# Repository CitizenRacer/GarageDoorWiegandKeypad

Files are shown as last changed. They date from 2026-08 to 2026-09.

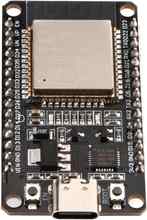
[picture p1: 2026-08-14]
docs/images/esp32s-30pin.jpg

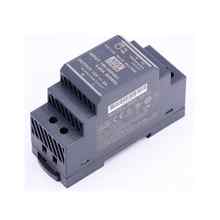
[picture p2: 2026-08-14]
docs/images/meanwell-hdr-30-12.jpg

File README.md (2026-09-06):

# Garage Door Keypad

ESPHome firmware and Home Assistant configuration for a classic ESP32-based garage-door Wiegand keypad controller.

The controller is an **ESP32S 30-pin USB-C NodeMCU development board with ESP32-WROOM-32 and CP2102**. The active outdoor reader/keypad is a **Retekess T-AC04** using Wiegand output.

## Release status

The repository firmware on `main` is **v22**. The last confirmed production deployment is **v22**.

v22 changes only the standalone `*` / `#` close shortcut. Firmware no longer trusts a cached Home Assistant garage-door state and no longer calls `cover.close_cover` directly. A standalone `*` or `#` now always delegates to the Home Assistant close-only API `script.garage_keypad_close_garage`, which refreshes RATGDO telemetry when needed and proceeds only when the refreshed state is positively `open`. Ambiguous telemetry fails closed, and this standalone path has no route that can open the garage or alter the alarm.

Valid PIN behavior remains unchanged from v21: Lock Code Manager validates the credential, invalid attempts are logged to Home Assistant Activity with the LCM reason and no PIN value, and accepted credentials call the guarded `script.garage_keypad_open_garage` flow.

The PIN path is:

```text
Retekess T-AC04 PIN
   |
   v
ESP32 key collector
   |
   | encrypted ESPHome native API
   v
lock_code_manager.use_credential
   |
   | LCM user / PIN / enabled state / conditions
   v
{ valid, user, reason }
   |
   +--> valid: script.garage_keypad_open_garage(person_name=<LCM user>)
   |
   +--> invalid: Activity entry with LCM reason; no garage action
```

The v20 production cutover established that valid physical PINs resolve to the correct LCM users, invalid PINs are rejected, PIN values do not appear in ESPHome logs, Debug Mode blocks opening during no-motion testing, and the production guarded path opens the garage after Debug Mode is intentionally disabled.

## Required runtime dependency

This project has a direct runtime dependency on **[Lock Code Manager](https://github.com/raman325/lock_code_manager)**, a Home Assistant custom integration. Use **LCM 5.3.0 or later**.

Lock Code Manager is the canonical source for keypad users and PINs. Adding, removing, enabling, disabling, or scheduling a keypad user should be done in LCM rather than by editing a YAML credential map.

The ESPHome package cannot install or enforce the presence of a Home Assistant custom integration. If LCM is missing, unavailable, or its action call fails, credential validation fails closed and firmware refuses garage operation.

For GitHub tooling, `.github/workflows/dependency-submission.yml` submits `raman325/lock_code_manager` as a **direct runtime dependency** to GitHub's Dependency Graph. This makes the relationship machine-readable in **Insights → Dependency graph** even though ESPHome YAML has no native manifest field for Home Assistant integration dependencies.

## Current access-control contract

Credential validation and physical garage operation are deliberately separate.

LCM answers **who is authorized**. `script.garage_keypad_open_garage` decides **whether and how the physical garage may move** for valid PINs. `script.garage_keypad_close_garage` is a separate close-only API for standalone `*` / `#` commands.

The guarded door-action layer uses these rules:

- If the garage cover state is exactly `open`, a valid PIN closes it. This branch does not alter the alarm.
- A standalone `*` or `#` never decides garage state in firmware. It always calls `script.garage_keypad_close_garage` when no PIN entry is in progress.
- The close-only Home Assistant script calls `cover.close_cover` immediately only when RATGDO already positively reports `open`.
- If RATGDO is not positively `open`, the close-only script presses `button.ratgdov25i_15cde7_query_status`, waits up to 3 seconds for a definitive `open` or `closed` state when needed, and requires the result to be exactly `open` before closing.
- If refreshed telemetry is `closed`, transitional, unavailable, unknown, or otherwise not positively `open`, the standalone close request does nothing. Ambiguous telemetry therefore fails closed.
- The standalone close-only script has no path that can open the garage and does not change the alarm.
- For valid PIN handling, opening is considered only when the guarded Home Assistant path positively establishes the required terminal state. Unknown, unavailable, or otherwise unsafe states fail closed.
- Opening requires `input_select.garage_keypad_alarm_restore_mode` to be exactly `none`.
- Opening requires `binary_sensor.garage_garage_keypad_debug_mode` to be exactly `off`.
- If the alarm is already disarmed, the garage may open without creating a restore marker.
- If the alarm is in a supported armed state, the script records the exact mode, disarms, positively confirms `disarmed`, records keypad ownership of that disarm, and only then opens.
- Supported armed modes are `armed_home`, `armed_away`, `armed_night`, `armed_vacation`, and `armed_custom_bypass`.
- Unsupported, unknown, unavailable, triggered, or otherwise non-disarmed alarm states block opening.
- The production live script verifies RATGDO motor activity and retries the opening request when needed before treating the operation as successful.
- When RATGDO reports `opening` or `closing` while the motor is off, the production valid-PIN script refreshes RATGDO status before deciding whether to open or close and fails closed if a definitive state cannot be established.
- Only after a confirmed actual opening does the kitchen Alexa announce `"<friendly user name> opened the garage door"`.

An LCM `lock_code_manager_credential_used` event means a credential was accepted. It is **not** proof that the garage moved; garage motion remains the responsibility of the guarded operation layer.

## Lock Code Manager configuration

The production keypad uses the lockless LCM entry **KOZ2 Locks**. Firmware uses its stable config-entry ID by default and reports the Garage Keypad as the credential source and the RATGDO cover as the target.

The firmware calls:

```yaml
lock_code_manager.use_credential
```

with:

```text
config_entry_id = configured KOZ2 Locks entry
code            = PIN entered on keypad
source          = Garage Keypad attribution entity
target          = cover.ratgdov25i_15cde7_door
```

LCM returns `valid`, `user`, and `reason`.

- `valid: true` -> firmware passes the returned friendly user name to `script.garage_keypad_open_garage`.
- `valid: false` -> firmware does not call the garage script. It logs a Home Assistant Activity entry such as `Credential rejected - Lock Code Manager reason: unknown_code`.
- action/response failure -> firmware fails closed and refuses garage operation.

No Activity entry contains the submitted PIN.

Enable **Allow the device to perform Home Assistant actions** for the Garage Keypad ESPHome integration entry. ESPHome and Home Assistant 2025.11.0 or later are required for reliable action-response capture.

## Debug Mode

v22 retains Debug Mode as an independent physical-operation safety control:

```yaml
keypad_debug_mode: "false"
```

The normal production setting is `false`. Set it to `true` only for an intentional no-motion/maintenance test and redeploy the firmware. The Home Assistant opening path fails closed unless `binary_sensor.garage_garage_keypad_debug_mode` positively reports `off`.

Debug Mode has nothing to do with credential logging. PINs are never intentionally logged in either mode. Debug Mode blocks opening but does not block closing an already-open garage.

## PIN confidentiality

There is no PIN HMAC, verifier map, HMAC generator, eFuse-key dependency, PIN sensor, or custom PIN-validation script in the v20-v22 firmware path.

The plaintext PIN exists only transiently in the ESPHome key collector and in the encrypted native-API request to `lock_code_manager.use_credential`. It is never intentionally published as an entity state, written to ESPHome logs, or written to Home Assistant Activity/Logbook.

Firmware logs only the PIN length and LCM validation result/reason. Rejected-credential Activity entries contain only the LCM reason.

## RFID status

RFID authorization is **disabled in v22**.

The firmware continues to decode and log 26/34/37-bit Wiegand RFID frames for commissioning, but it does not submit RFID IDs to LCM and does not operate the garage from an RFID credential. The LCM external-credential path used by this project is PIN-oriented; RFID identifiers are not represented as PINs simply to force them through the integration.

See [`docs/RFID_ACCESS_DESIGN.md`](docs/RFID_ACCESS_DESIGN.md).

## Wiegand diagnostics

RFID commissioning diagnostics may log:

```text
RFID tag received: <decoded credential> (authorization disabled)
Wiegand RFID/raw frame: <bits> bits, value=0x<raw>
```

The raw Wiegand logger is intentionally restricted to frames **greater than 8 bits**. It must never raw-log 4-bit or 8-bit frames because those frames are keypad keystrokes and could disclose PIN digits.

## Standalone `*` / `#` close-only behavior

Wiegand key 10 (`*`) and key 11 (`#`) have two contexts:

- after numeric PIN digits, `*` remains PIN clear and `#` remains PIN submit exactly as before;
- with no numeric PIN entry in progress, either key calls `script.garage_keypad_close_garage`.

Firmware does **not** import or inspect garage-door state for this shortcut in v22. It does not call `cover.close_cover` directly and does not route the command through `script.garage_keypad_open_garage`.

`script.garage_keypad_close_garage` is intentionally structurally close-only:

1. If RATGDO already positively reports `open`, it calls `cover.close_cover`.
2. Otherwise it presses `button.ratgdov25i_15cde7_query_status`.
3. If necessary, it waits up to 3 seconds for `open` or `closed`.
4. It requires the final state to be exactly `open` before issuing a close.
5. Any other result does nothing.

Because the script contains no open action and no alarm action, a standalone `*` / `#` command cannot open the garage or change alarm state. Stale, transitional, unavailable, unknown, or otherwise ambiguous telemetry fails closed.

## Alarm transaction and recovery behavior

The persistent ownership marker is:

```text
input_select.garage_keypad_alarm_restore_mode
```

with options:

```text
none
armed_home
armed_away
armed_night
armed_vacation
armed_custom_bypass
```

The marker means the keypad flow itself disarmed the alarm and therefore owns a pending restoration.

When the garage later closes, the companion automation restores the saved mode only when the keypad owns that restore. If somebody manually re-arms first, the automation preserves that state and clears the keypad marker.

The checked-in automation is [`homeassistant/garage-keypad-automation.yaml`](homeassistant/garage-keypad-automation.yaml).

## Hardware and wiring

Installed Wiegand signal path:

```text
T-AC04 Green D0 -> level shifter HV3/LV3 -> ESP32 GPIO22
T-AC04 White D1 -> level shifter HV2/LV2 -> ESP32 GPIO19
```

The firmware defaults to GPIO22 for D0 and GPIO19 for D1. See [`docs/BOM.md`](docs/BOM.md) for the as-built bill of materials.

## ESPHome package and Device Builder

The repository firmware package is [`esphome/garage-keypad.yaml`](esphome/garage-keypad.yaml), currently firmware **v22**.

Firmware versioning is explicit: increment `firmware_version` whenever `esphome/garage-keypad.yaml` itself is checked in with a firmware change. Documentation/workflow-only changes do **not** require a firmware-version increment.

A local Device Builder wrapper supplies secrets and imports the package from `main`. See [`esphome/device-builder-wrapper.example.yaml`](esphome/device-builder-wrapper.example.yaml).

Required local substitutions include Wi-Fi credentials, OTA password, fallback AP password, and the ESPHome API Noise key. The LCM config-entry ID and source/target entities are normal non-secret substitutions and can be overridden if the Home Assistant installation changes.

The production local wrapper should use:

```yaml
keypad_debug_mode: "false"
```

Old v19 wrapper extensions such as `generated_pin_hmac` or `keypad_debug_logging` are obsolete and must not be carried forward.

## Continuous integration

`.github/workflows/esphome.yml` validates and compiles the production ESPHome package on every push and pull request, and can also be run manually with `workflow_dispatch`. CI is pinned to **ESPHome 2026.8.2** and runs on a standard GitHub-hosted Ubuntu runner.

The workflow creates synthetic CI-only Wi-Fi, OTA, fallback-AP, and API-encryption values; no production credentials are stored in the repository or required by GitHub Actions. It validates a local package wrapper, validates the checked-in production Device Builder wrapper on `main`, and then compiles `esphome/garage-keypad.yaml` through the CI wrapper. CI only verifies that the configuration can be resolved and built; it does not deploy firmware to the physical keypad.

## Home Assistant files

[`homeassistant/garage-keypad-script.yaml`](homeassistant/garage-keypad-script.yaml) documents the common guarded valid-PIN door-action API. The production live `script.garage_keypad_open_garage` contains additional RATGDO status-refresh and motor-start verification/retry behavior; do not replace that more capable live script with the simpler checked-in baseline.

v22 also requires the live Home Assistant script `script.garage_keypad_close_garage` for standalone `*` / `#`. That script is close-only: it refreshes RATGDO status when the door is not already positively `open`, requires a final `open` state, and otherwise performs no action. It must never contain an open action or alarm-management path.

[`homeassistant/garage-keypad-automation.yaml`](homeassistant/garage-keypad-automation.yaml) contains keypad-owned alarm restoration and manual-rearm ownership-clearing logic.

Required helper:

```text
input_select.garage_keypad_alarm_restore_mode
```

The old `garage_keypad_users.yaml`, PIN HMAC validator, RFID HMAC validator, and HMAC-generation helper are obsolete for the LCM production architecture. See [`docs/LCM_MIGRATION.md`](docs/LCM_MIGRATION.md) for rollback-cleanup guidance.

## Security model

- PINs are stored and managed by Lock Code Manager.
- A keypad submission travels to Home Assistant through ESPHome's encrypted native API.
- No entity publishes the PIN, avoiding Recorder history of keypad codes.
- The firmware never intentionally logs plaintext PINs.
- Invalid-attempt Activity entries expose the LCM reason, not the submitted PIN.
- Standalone `*` / `#` close requests are delegated to a Home Assistant script that is structurally incapable of opening the garage.
- Firmware does not trust cached garage state for standalone close commands; ambiguous RATGDO telemetry is refreshed and still fails closed unless the result is positively `open`.
- A fully compromised Home Assistant installation can already directly operate the garage and is outside the keypad-validation threat model.
- The previously burned classic-ESP32 eFuse BLK3 bits cannot be erased, but v20-v22 do not read or use them.
- Debug Mode remains an absolute opening lockout, not a closing lockout.

## Migration and rollback

The v19 HMAC-to-v20 LCM production cutover is complete. v22 retains the same LCM credential architecture and v21 rejection logging; it changes only the standalone close shortcut to delegate all state validation to the Home Assistant close-only script.

See [`docs/LCM_MIGRATION.md`](docs/LCM_MIGRATION.md) for the completed validation record and remaining rollback cleanup.

Until the old live HMAC scripts/file are intentionally removed, reinstalling v19 remains a rollback option. Once those live rollback artifacts are deleted, LCM is the sole supported credential authority.

## Repository structure

```text
GarageDoorWiegandKeypad/
├── .github/
│   └── workflows/
│       ├── dependency-submission.yml
│       └── esphome.yml
├── README.md
├── cad/
├── docs/
│   ├── BOM.md
│   ├── LCM_MIGRATION.md
│   └── RFID_ACCESS_DESIGN.md
├── esphome/
│   ├── garage-keypad.yaml
│   └── device-builder-wrapper.example.yaml
└── homeassistant/
    ├── garage-keypad-script.yaml
    └── garage-keypad-automation.yaml
```

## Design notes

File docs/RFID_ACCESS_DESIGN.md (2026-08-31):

# RFID access status

Production firmware v20 deliberately **does not authorize RFID credentials**.

The Retekess T-AC04 and ESPHome Wiegand component still decode 26-, 34-, and 37-bit RFID frames, and commissioning diagnostics remain available:

```text
RFID tag received: <decoded credential> (authorization disabled)
Wiegand RFID/raw frame: <bits> bits, value=0x<raw>
```

Raw logging remains restricted to frames greater than 8 bits so 4-bit/8-bit keypad keystroke frames are never raw-logged.

## Production behavior

The v20 production cutover validated PIN access through Lock Code Manager. RFID was intentionally excluded from that cutover and cannot operate the garage.

The rule is:

```text
RFID frame -> decode/diagnose -> NO authorization -> NO garage action
```

An RFID frame does not call `lock_code_manager.use_credential`, does not call `script.garage_keypad_open_garage`, and does not open or close the garage.

## Why authorization is disabled

The project moved PIN management to Lock Code Manager in v20 and removed the custom HMAC credential system from the firmware path. Although LCM has credential-type concepts, the managed external-credential path currently used by this project is PIN-oriented.

Treating a raw RFID identifier as a PIN would create misleading credential semantics and make a later proper RFID migration harder. The old HMAC-based RFID authorization path should not be reintroduced as an interim design.

## Diagnostics and confidentiality

RFID commissioning logs can expose decoded/static RFID identifiers to anyone who can read ESPHome logs. Those identifiers should therefore be treated as credential material even though RFID authorization is disabled.

The raw Wiegand logger must continue to enforce `bits > 8`. Four-bit and eight-bit frames are keypad keystrokes and must never be raw-logged because doing so could expose PIN digits.

## Future target

When Lock Code Manager supports the intended RFID credential type end to end for external readers, the target flow is:

```text
T-AC04 RFID
   |
   v
ESPHome Wiegand decoder
   |
   v
LCM RFID credential validation
   |
   v
friendly user
   |
   v
guarded script.garage_keypad_open_garage
```

At that point the project should use LCM's real RFID credential type and unified credential-used event while preserving the same guarded physical-operation layer used by PINs.

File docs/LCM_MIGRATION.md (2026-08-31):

# Lock Code Manager migration

## Status

The v19 HMAC-to-v20 Lock Code Manager migration is **complete in production**.

Firmware v20 is merged to `main`, deployed to the physical Garage Keypad, and validated through the full production path. Lock Code Manager is now the canonical PIN/user store.

The only remaining migration work is optional rollback cleanup on the live Home Assistant instance: remove the obsolete v19 HMAC validators, HMAC generator, and credential-map file after deciding that v19 rollback is no longer needed.

## Production architecture

```text
Retekess T-AC04 PIN
   |
   v
ESPHome v20 key collector
   |
   | encrypted native API
   v
lock_code_manager.use_credential
   |
   v
{ valid, user, reason }
   |
   +--> valid: script.garage_keypad_open_garage(person_name=<LCM user>)
   |
   +--> invalid: stop; no garage action
```

LCM owns credential validity and user identity. `script.garage_keypad_open_garage` remains the guarded physical-operation layer and must not be bypassed.

## Completed cutover record

### 1. LCM population and direct validation — complete

The production lockless `KOZ2 Locks` entry was populated with the intended production keypad users/PINs and validated with `lock_code_manager.use_credential` before firmware cutover.

Expected response fields are:

```text
valid
user
reason
```

Invalid reasons observed/expected include `unknown_code`, `user_disabled`, and `condition_not_met`.

### 2. v20 merged to `main` — complete

Pull request #1, `Firmware v20: migrate keypad PIN validation to Lock Code Manager`, was merged from `lcm-native-credentials` into `main`.

The firmware remains version `20`; the merge itself did not create a new firmware version.

### 3. First v20 deployment with Debug Mode on — complete

The local Device Builder wrapper was updated for v20 and deployed with:

```yaml
substitutions:
  keypad_debug_mode: "true"
```

Stale v19 wrapper configuration referencing `generated_pin_hmac` was removed because that entity no longer exists in v20.

Home Assistant then reported firmware version `20` and Debug Mode `on`.

### 4. Physical no-motion test — passed

Physical keypad submissions were tested while Debug Mode remained on.

Observed results:

- valid physical PIN submissions reached `lock_code_manager.use_credential`;
- LCM resolved valid credentials to the correct friendly users;
- invalid PINs were rejected as `unknown_code`;
- invalid credentials did not reach the guarded garage-operation path;
- ESPHome logs contained PIN length and validation results but not the actual PIN values;
- accepted credentials did not move the garage while Debug Mode was on.

This verified the intended chain through the physical Wiegand keypad, ESPHome key collector, LCM, and the guarded Home Assistant operation script without allowing door motion.

### 5. Production deployment with Debug Mode off — complete

After the no-motion test passed, v20 was redeployed with:

```yaml
keypad_debug_mode: "false"
```

The Debug Mode binary sensor reported `off`.

A valid physical keypad PIN then successfully opened the garage through the normal v20 LCM path and the existing guarded `script.garage_keypad_open_garage` operation layer.

The production cutover is therefore complete.

## Current production requirements

- Lock Code Manager remains the canonical PIN/user database.
- Garage Keypad ESPHome integration must retain **Allow the device to perform Home Assistant actions**.
- ESPHome and Home Assistant 2025.11.0 or later are required for reliable `homeassistant.action` response capture.
- Production `keypad_debug_mode` should be `"false"`.
- The guarded `script.garage_keypad_open_garage` must remain the only valid-credential path to physical garage operation.
- The production live garage script's RATGDO motor-start verification/retry behavior should be preserved.
- PIN values must never be intentionally logged or exposed as entity state/history.
- Raw 4-bit and 8-bit Wiegand frames must never be logged.
- RFID authorization remains disabled in v20.

## Remaining rollback cleanup

The old HMAC path is no longer used by production v20. It may remain temporarily on the live Home Assistant installation only as rollback material.

When rollback is no longer desired, verify there are no active references and remove the obsolete live artifacts:

- `script.garage_keypad_validate_hmac`;
- `script.garage_keypad_validate_rfid_hmac`;
- the administrative HMAC generator script/action;
- the old `garage_keypad_users.yaml` credential file;
- stale Home Assistant references to `generate_pin_hmac`, `Generated PIN HMAC`, or the old validator names;
- stale Device Builder wrapper configuration such as `keypad_debug_logging` or `!extend generated_pin_hmac`.

Do **not** remove `script.garage_keypad_open_garage` or the alarm-restoration automation; those remain part of the production design.

The ESP32's previously fused BLK3 bits are permanent and cannot be erased. Firmware v20 simply does not read or use them.

## Rollback

Until the live HMAC rollback artifacts are removed, rollback remains possible by reinstalling firmware v19 and restoring/using the legacy HMAC validator path.

After those artifacts are intentionally deleted, v20 + Lock Code Manager becomes the sole supported credential architecture.

## RFID

RFID authorization is deliberately disabled in v20. The Wiegand decoder and diagnostics remain available, but RFID IDs are not sent to LCM as fake PINs and cannot operate the garage.

Revisit RFID only when the managed LCM credential flow supports the intended RFID credential type end to end. See [`RFID_ACCESS_DESIGN.md`](RFID_ACCESS_DESIGN.md).

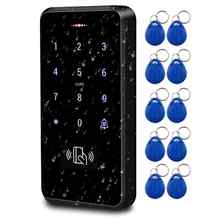
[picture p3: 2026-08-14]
docs/images/s20-id-keypad.jpg

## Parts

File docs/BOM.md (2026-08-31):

# Garage Door Keypad — As-Built Bill of Materials

This is the hardware bill of materials for the installed Garage Door Keypad system. It documents the parts actually selected for the project rather than a generic reference design.

> **Amazon Associates disclosure:** As an Amazon Associate I earn from qualifying purchases.

Amazon links supplied by the project owner are preserved as-is because they already contain the owner's associate attribution. Other Amazon links use associate tag `k-20`.

## Core electronics

| Qty | Part | Purpose | Purchase link |
|---:|---|---|---|
| 1 | Retekess T-AC04 Wiegand keypad / RFID reader | Active outdoor PIN keypad and RFID reader | [Amazon](https://www.amazon.com/dp/B07QSFR4FF?tag=k-20) |
| 1 | 30-pin ESP32-WROOM-32 USB-C development board, CP2102 | ESPHome controller | [Amazon](https://www.amazon.com/dp/B0CR5Y2JVD?tag=k-20) |
| 1 | ESP32 DIN-rail carrier with integrated DC-DC buck converter | DIN mounting, screw-terminal breakout, and regulated ESP32 power from the 12 V supply | [AliExpress](https://a.aliexpress.com/_mLu7eDp) |
| 1 | MEAN WELL HDR-30-12 DIN-rail power supply | 120 VAC to 12 VDC power supply for the keypad/control system | [Amazon](https://www.amazon.com/dp/B06XWRWSHT?tag=k-20) |
| 1 | HiLetgo 4-channel BSS138 bidirectional logic-level converter | Wiegand D0/D1 level shifting between the reader side and ESP32 logic | [Amazon](https://www.amazon.com/dp/B07F7W91LC?tag=k-20) |
| 1 | Custom 3D-printed HiLetgo DIN-rail cable-clamp mount | Secures the level-shifter PCB to the DIN rail | Repository CAD: [`../cad/HiLetgo_Level_Shifter_DIN_CableClamp.scad`](../cad/HiLetgo_Level_Shifter_DIN_CableClamp.scad) |

### Power architecture

There is **no separate buck-converter module** in the finished system. The ESP32 DIN-rail carrier has the DC-DC converter built in.

```text
120 VAC
   |
   v
MEAN WELL HDR-30-12
   |
   +---- 12 VDC ----> Retekess T-AC04
   |
   +---- 12 VDC ----> ESP32 DIN carrier
                         |
                         +--> integrated buck converter --> ESP32
```

## Enclosure and DIN hardware

| Qty | Part | Purpose | Purchase link |
|---:|---|---|---|
| 1 | Clear-cover electrical enclosure / control box | Houses the DIN rail, power supply, ESP32 carrier, and level shifter | [Amazon](https://amzn.to/4xVVENP) |
| 1 | VAMRONE 35 mm x 7.5 mm slotted aluminum DIN rail | Mounting rail inside the enclosure | [Amazon](https://www.amazon.com/dp/B088FC2KB8?tag=k-20) |
| As needed | CGELE PG7 IP68 nylon cable glands, 3–7 mm | Cable entry, strain relief, and enclosure sealing | [Amazon](https://www.amazon.com/dp/B09GV9Q79C?tag=k-20) |
| 1 | 3 ft 16/3 SJTW grounded power cord | AC mains feed to the HDR-30-12 | [Amazon](https://www.amazon.com/dp/B07BQCMPF2?tag=k-20) |

## Wire and cable

| Qty | Part | Purpose | Purchase link |
|---:|---|---|---|
| As needed | 22 AWG, 4-conductor, stranded CMR security/access-control cable | Cable run from the outdoor T-AC04 to the control enclosure | [Amazon](https://amzn.to/3U5sbm1) |
| As needed | 18 AWG PVC stranded hookup wire | Internal low-voltage power wiring | [Amazon](https://amzn.to/3UrP2YX) |

## Wiegand wiring

The installed Wiegand signal path is:

```text
Retekess T-AC04 Green D0 -> level shifter HV3/LV3 -> ESP32 GPIO22
Retekess T-AC04 White D1 -> level shifter HV2/LV2 -> ESP32 GPIO19
```

The T-AC04 is powered from the 12 V supply. The ESP32 carrier is also fed from 12 V and uses its integrated buck converter to power the ESP32.

## Existing-system dependencies

These are required by the complete installed system but are not part of the keypad control-box purchase BOM:

- LiftMaster garage-door opener
- ratgdo garage-door interface
- Home Assistant
- ESPHome Device Builder
- Lock Code Manager for production PIN/user authorization
- Home Assistant alarm integration used by the guarded opening workflow
- Kitchen Alexa target used for successful-opening announcements

## Current software relationship

The installed classic ESP32-WROOM-32 controller is running **firmware v20**.

v20 sends completed keypad PINs over the encrypted ESPHome native API to `lock_code_manager.use_credential`. Lock Code Manager is the production credential database. Valid credentials are passed by friendly user name to the guarded Home Assistant garage-operation script.

RFID authorization is disabled in v20 even though the T-AC04 hardware can emit RFID Wiegand frames.

The ESP32 still physically contains the BLK3 eFuse bits provisioned by the former v19 HMAC design. Those bits are permanent, but v20 does not read or use them.

## Notes

- The active reader is the **Retekess T-AC04**.
- The ESP32 is the classic ESP32-WROOM-32 design currently used by production firmware v20.
- The HiLetgo level shifter is mounted using the project's checked-in DIN-rail cable-clamp part.
- PINs, Lock Code Manager credential data, raw production RFID credential values, and other live authorization material are intentionally **not** part of this document or repository.

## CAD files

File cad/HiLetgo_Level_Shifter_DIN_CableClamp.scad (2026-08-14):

// HiLetgo level-shifter DIN mount — Cable Clamp remix
// Design version: 6
// VERSIONING RULE: Increment design_version by 1 for every repository check-in of this design.
//
// This is the official HiLetgo level-shifter DIN holder for this project.
// It is based on the user-supplied DIN_Rail_Cable_Clamp.step.
//
// What changed from the cable clamp:
//   1. The two center cable-rest arms are removed completely.
//   2. The two rectangular cable-tie slots in the spine are filled.
//   3. A true full-width top/bottom slide cradle is added for the HiLetgo PCB.
//   4. The PCB is parallel to the DIN rail and slides in from either X side.
//   5. v4 flips the PCB cradle to the OPPOSITE (+Y) face of the DIN body.
//      The v3 cradle was on the cable-clamp-arm side; this version mounts the
//      PCB on the other side of the central DIN spine.
//   6. v5 widens the entire DIN clip body to exactly match the PCB cradle width.
//      There is no longer a wider cradle sitting on a narrower DIN body.
//   7. v6 renames the official source file to remove the ChatGPT prefix.
//
// The original STEP is effectively a 6 mm-wide extrusion. To keep this
// OpenSCAD source compact and robust, its center-plane Y/Z profile was captured
// from the STEP-derived mesh and simplified to ~0.03 mm. In v5 that same DIN
// spring/hook profile is extruded to the PCB cradle width instead of the original
// 6 mm, so the complete mount has one consistent width.

$fn = 48;
design_version = 6;

// ---------- HiLetgo PCB ----------
pcb_z = 15.3;             // board height in installed orientation
pcb_x = 12.6;             // board width across the DIN clip
pcb_t = 1.6;              // board thickness (Y)
pcb_edge_clear = 0.30;     // top/bottom clearance
pcb_face_clear = 0.25;     // front/rear clearance

// ---------- Mount / cradle ----------
cradle_side_margin = 0.60;
mount_width = pcb_x + 2*cradle_side_margin;  // 13.8 mm: DIN body and PCB cradle match
spine_front_y = 4.80;      // cable-arm side of the remaining center spine
spine_back_y = 9.00;       // opposite face of the DIN spine

// v4: PCB holder is on the +Y side of the spine (opposite v3).
// The board sits just outside the spine and slides in from either X side.
pcb_inner_y = spine_back_y + 0.80;
pcb_outer_y = pcb_inner_y + pcb_t;
slot_inner_y = pcb_inner_y - pcb_face_clear;
slot_outer_y = pcb_outer_y + pcb_face_clear;

board_half_z = pcb_z/2;
channel_inner_z = board_half_z + pcb_edge_clear;
channel_wall_t = 1.45;
channel_outer_z = channel_inner_z + channel_wall_t;
edge_overlap = 1.10;
outer_lip_t = 0.80;
lead_in = 0.60;

cradle_width_x = mount_width;  // exactly the same width as the DIN clip body

// ---------- STEP-derived 2D DIN profile ----------
// Coordinates are [Y depth, Z vertical].  Only the two DIN-spring voids are
// retained as holes.  The original rectangular cable-tie slots are intentionally
// NOT subtracted, so they become solid in this PCB-mount remix.
source_outer = [
    [0.0000, -16.3500],
    [0.0000, -17.3500],
    [-1.0000, -17.3500],
    [-1.2679, -16.3500],
    [-2.2679, -16.3500],
    [-5.1675, -18.0355],
    [-5.5943, -18.4518],
    [-5.8794, -18.9754],
    [-5.9994, -19.6095],
    [-5.9859, -24.2194],
    [-4.8419, -28.5652],
    [-4.5932, -29.1009],
    [-4.3446, -29.4072],
    [-4.0813, -29.6307],
    [-3.7387, -29.8263],
    [-3.4123, -29.9393],
    [-2.9728, -29.9994],
    [-1.0000, -30.0000],
    [-1.0000, -28.4000],
    [-2.5064, -28.3945],
    [-2.7320, -28.3004],
    [-2.8860, -28.1106],
    [-3.1812, -27.0372],
    [-3.1905, -26.8515],
    [-3.1313, -26.6752],
    [-3.0118, -26.5328],
    [-2.8485, -26.4439],
    [-2.6640, -26.4208],
    [5.4219, -28.5823],
    [5.6620, -28.7130],
    [5.8577, -28.9039],
    [6.1149, -29.4654],
    [6.2722, -29.6858],
    [6.4830, -29.8560],
    [6.7079, -29.9564],
    [6.9753, -29.9997],
    [9.0000, -30.0000],
    [9.0000, 30.0000],
    [3.0550, 29.9975],
    [2.5177, 29.8959],
    [1.9872, 29.6239],
    [1.6886, 29.3603],
    [1.4226, 29.0000],
    [-2.7321, 21.8038],
    [-2.9499, 21.2489],
    [-2.9994, 20.8537],
    [-3.0000, 17.3500],
    [-2.4641, 15.3500],
    [-1.7359, 15.3500],
    [-1.2000, 17.3500],
    [0.0000, 17.3500],
    [0.0099, 14.1509],
    [0.1206, 13.6660],
    [0.3761, 13.1825],
    [0.6035, 12.9183],
    [0.8734, 12.6975],
    [1.1774, 12.5270],
    [1.5550, 12.4001],
    [1.9501, 12.3506],
    [4.0143, 12.3490],
    [4.3492, 12.2596],
    [4.6306, 12.0247],
    [4.7784, 11.7112],
    [4.7805, 11.3446],
    [4.6238, 11.0132],
    [4.2831, 10.7568],
    [4.0647, 10.7016],
    [3.8396, 10.7075],
    [-1.0000, 12.0000],
    [-5.1490, 11.9888],
    [-5.4339, 11.9010],
    [-5.6802, 11.7331],
    [-5.8782, 11.4783],
    [-5.9802, 11.1981],
    [-5.9888, 8.8510],
    [-5.8400, 8.4575],
    [-5.5214, 8.1467],
    [-5.2708, 8.0374],
    [-5.0249, 8.0003],
    [-1.0000, 8.0000],
    [2.7186, 6.9998],
    [3.4513, 6.6486],
    [4.0135, 6.1689],
    [4.4757, 5.5006],
    [4.7262, 4.8053],
    [4.8000, 4.1439],
    [4.7963, -4.2920],
    [4.7262, -4.8053],
    [4.5965, -5.2301],
    [4.4055, -5.6311],
    [4.1573, -5.9994],
    [3.8030, -6.3773],
    [3.4513, -6.6486],
    [3.0634, -6.8649],
    [2.5765, -7.0417],
    [-1.0000, -8.0000],
    [-5.1981, -8.0198],
    [-5.4783, -8.1218],
    [-5.6982, -8.2841],
    [-5.8782, -8.5217],
    [-5.9749, -8.7775],
    [-6.0000, -11.0000],
    [-5.9691, -11.2468],
    [-5.8660, -11.5000],
    [-5.6802, -11.7331],
    [-5.4562, -11.8899],
    [-5.1981, -11.9802],
    [-1.0000, -12.0000],
    [3.5893, -10.7716],
    [3.9095, -10.7551],
    [4.2407, -10.8515],
    [4.5847, -11.1292],
    [4.7753, -11.5281],
    [4.8028, -13.4247],
    [4.8521, -13.6685],
    [4.9600, -13.8925],
    [5.1572, -14.1160],
    [5.4347, -14.2809],
    [5.6757, -14.3422],
    [6.1981, -14.3698],
    [6.5425, -14.5100],
    [6.8400, -14.8075],
    [6.9848, -15.1764],
    [6.9749, -15.5725],
    [6.8119, -15.9337],
    [6.5214, -16.2033],
    [6.1736, -16.3348],
];

lower_spring_void = [
    [-4.5107, -18.7997],
    [-2.0306, -17.3676],
    [-1.7673, -18.3500],
    [1.0000, -18.3500],
    [1.0000, -17.3500],
    [6.0498, -17.3512],
    [6.3420, -17.4103],
    [6.6235, -17.5682],
    [6.8400, -17.8075],
    [6.9691, -18.1032],
    [6.9888, -18.9990],
    [6.9115, -19.2613],
    [6.7660, -19.4928],
    [6.5633, -19.6762],
    [6.2948, -19.8056],
    [6.0000, -19.8500],
    [-2.5996, -19.8550],
    [-2.9113, -19.9385],
    [-3.1982, -20.1341],
    [-3.4010, -20.4161],
    [-3.4950, -20.7504],
    [-3.4851, -22.4854],
    [-3.3429, -22.8514],
    [-3.0504, -23.1483],
    [-2.7588, -23.2793],
    [5.3999, -25.4770],
    [5.7740, -25.7604],
    [5.9721, -26.1589],
    [5.9776, -26.6039],
    [5.7740, -27.0267],
    [5.5736, -27.2127],
    [5.3303, -27.3374],
    [5.0623, -27.3916],
    [4.7896, -27.3712],
    [-4.2588, -24.9479],
    [-4.6301, -24.7585],
    [-4.8919, -24.4342],
    [-4.9973, -24.0560],
    [-4.9997, -19.6345],
    [-4.9626, -19.3886],
    [-4.8660, -19.1594],
    [-4.7159, -18.9612],
];

upper_spring_void = [
    [4.8000, 28.8000],
    [4.8000, 13.5500],
    [1.8415, 13.5659],
    [1.6174, 13.6474],
    [1.4136, 13.8059],
    [1.2708, 14.0210],
    [1.2062, 14.2505],
    [1.2000, 18.5500],
    [-1.8000, 18.5500],
    [-1.7841, 20.9624],
    [-1.6928, 21.2038],
    [2.5419, 28.5142],
    [2.7721, 28.7026],
    [3.0552, 28.7938],
];

module source_profile_2d() {
    difference() {
        polygon(points=source_outer);
        polygon(points=lower_spring_void);
        polygon(points=upper_spring_void);
    }
}

module rect_yz(y0,y1,z0,z1) {
    translate([y0,z0]) square([y1-y0,z1-z0], center=false);
}

module clip_without_cable_arms_2d() {
    difference() {
        source_profile_2d();
        // Removes both center cable-rest arms while stopping just before the
        // central spine.  Upper/lower DIN spring hooks are untouched.
        rect_yz(-6.20, spine_front_y-0.02, -13.25, 13.25);
    }
}

module din_clip_body() {
    // Original DIN clip, with the cable-rest arms removed.
    multmatrix([
        [0,0,1,0],
        [1,0,0,0],
        [0,1,0,0],
        [0,0,0,1]
    ])
        linear_extrude(height=mount_width, center=true, convexity=20)
            clip_without_cable_arms_2d();
}

module pcb_cradle() {
    // v4 holder is on the +Y face of the DIN spine.
    // The PCB slides along X between top/bottom edge channels.
    xw = cradle_width_x;
    bridge_y0 = spine_back_y - 0.25;  // overlap body for a robust union
    bridge_y1 = slot_outer_y + outer_lip_t + lead_in;

    // TOP channel: overhead bridge/wall.
    translate([0, (bridge_y0+bridge_y1)/2,
               (channel_inner_z+channel_outer_z)/2])
        cube([xw, bridge_y1-bridge_y0,
              channel_outer_z-channel_inner_z], center=true);
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

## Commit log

2026-08-14 Fix firmware target for ESP32-D0WD-V3
2026-08-14 Update README for classic ESP32 hardware
2026-08-14 Document exact ESP32 board and LED behavior
2026-08-14 Add GPIO2 blue connection status LED
2026-08-14 Document blue connection status LED
2026-08-14 Use double-blink LED pattern when Home Assistant is disconnected
2026-08-14 Track Home Assistant API client explicitly
2026-08-14 Add v1 DIN rail mount for HiLetgo level shifter
    [ChatGPT_HiLetgo_Level_Shifter_DIN_Mount.scad]
2026-08-14 Update level shifter DIN mount to measured PCB dimensions v2
    [ChatGPT_HiLetgo_Level_Shifter_DIN_Mount.scad]
2026-08-14 Redesign level shifter DIN mount as side-profile snap clip v3
    [ChatGPT_HiLetgo_Level_Shifter_DIN_Mount.scad]
2026-08-14 Redesign HiLetgo DIN mount using supplied spring clip (v4)
    [ChatGPT_HiLetgo_Level_Shifter_DIN_Mount.scad]
2026-08-14 Remove center hole from HiLetgo DIN mount (v5)
    [ChatGPT_HiLetgo_Level_Shifter_DIN_Mount.scad]
2026-08-14 v6: remove center hole without bump-out
    [ChatGPT_HiLetgo_Level_Shifter_DIN_Mount.scad]
2026-08-14 v7: remove side holes and make PCB clip full width
    [ChatGPT_HiLetgo_Level_Shifter_DIN_Mount.scad]
2026-08-14 v8: rebuild HiLetgo DIN mount as single manifold extrusion
    [ChatGPT_HiLetgo_Level_Shifter_DIN_Mount.scad]
2026-08-14 Add alternate HiLetgo DIN cable-clamp mount design v1
2026-08-14 Replace cable clamp with OpenSCAD HiLetgo PCB mount v2
    [ChatGPT_HiLetgo_Level_Shifter_DIN_CableClamp.scad]
2026-08-14 Remove obsolete CadQuery level-shifter mount source
2026-08-14 Fix HiLetgo PCB cradle in alternate OpenSCAD DIN mount v3
    [ChatGPT_HiLetgo_Level_Shifter_DIN_CableClamp.scad]
2026-08-14 Flip alternate HiLetgo PCB cradle to opposite side (v4)
    [ChatGPT_HiLetgo_Level_Shifter_DIN_CableClamp.scad]
2026-08-14 Widen alternate HiLetgo DIN body to match PCB cradle v5
    [ChatGPT_HiLetgo_Level_Shifter_DIN_CableClamp.scad]
2026-08-14 Remove superseded HiLetgo level shifter DIN mount
    [ChatGPT_HiLetgo_Level_Shifter_DIN_Mount.scad]
2026-08-14 Rename official HiLetgo level shifter DIN holder
    [HiLetgo_Level_Shifter_DIN_CableClamp.scad]
2026-08-14 Remove old ChatGPT-prefixed level shifter holder filename
    [ChatGPT_HiLetgo_Level_Shifter_DIN_CableClamp.scad]
2026-08-14 Add ESP32 terminal board image for BOM
2026-08-14 Add project BOM, purchase links, and reference images
2026-08-14 Firmware v2: expose ESP32 temperature sensor
2026-08-14 Document ESP32 temperature sensor
2026-08-14 Add Device Builder wrapper example
2026-08-14 Document GitHub-backed Device Builder workflow
2026-08-14 Add uploaded BOM reference images
2026-08-14 Suppress intentional GPIO2 strapping warning; firmware v4
2026-08-14 Document intentional GPIO2 strapping-warning suppression
2026-08-14 Use uploaded BOM images in README
2026-08-15 Add Wiegand keypad PIN collection and HA submission
2026-08-15 Document keypad debug and Wiegand pin overrides
2026-08-15 Document Wiegand PIN collection and debug logging
2026-08-15 Add Home Assistant PIN validation script
2026-08-15 Document Home Assistant PIN validation workflow
2026-08-15 Add debug keypad value sensor
2026-08-17 Document HMAC PIN verifier design and threat model
2026-08-17 Replace plaintext PIN examples with HMAC verifier map
2026-08-21 Update PIN HMAC design for live access control
2026-08-21 Default Device Builder wrapper to production debug mode
2026-08-21 Add as-built hardware bill of materials
2026-08-31 Update Device Builder wrapper for v20 debug mode
2026-08-31 Docs: update BOM for production v20
2026-08-31 Docs: update v20 Device Builder wrapper example
2026-11-02 Optimize ESP32 framework for garage keypad firmware v24
2026-11-02 Document v24 ESP32 optimization and hardware compatibility
